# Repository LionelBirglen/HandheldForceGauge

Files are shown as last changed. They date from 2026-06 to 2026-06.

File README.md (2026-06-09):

# Handheld Force Gauge
CAD and programs for a quick and simple handheld force gauge. User interface allows for changing units (N/kg), setting tare (zeroing), recording min/max values, and switching screen orientation. Onscreen values are broadcasted with Bluetooth and a local Python script allows for realtime display and data recording into a csv file. 

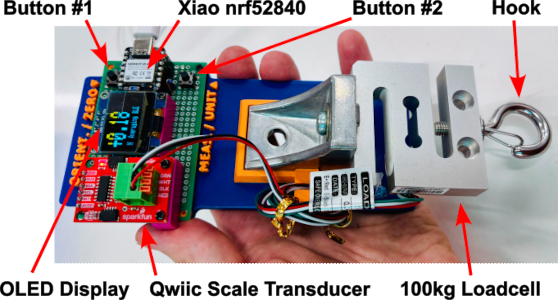
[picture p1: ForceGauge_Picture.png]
Force Gauge Picture

Force Gauge Video
<br/><br/>

## Instructions
1. 3D print ForceGauge_BasePlate.stp, Color change for the text layer is suggested
2. purchase all components, see BOM below
3. solder protoboard according to ForceGauge_Schematic.pdf
4. assemble components on protoboard
5. upload and run the Arduino program ForceGauge_Program.ino on the XIAO nrf52840 module (compile w/ mbed-enabled)
6. plug the usb-c connector to a suitable power supply
7. use the sensor! Tactile switches have two functions each, **selectable with short or long press** of the button:
8. if bluetooth communication is desired run ForceGauge_Python_BLE_Logger.py from your local machine where Python is installed, a window will open displaying the values read by the sensor and the program will record them in a csv file with timestamps.<br/>

**Notes:**
- local recording will overwrite the previous file if it exists, **rename your files if you want to keep them!**
- power can be provided by a standard phone/laptop usb-c charger or a power bank for maximal portability. Careful though, certain power banks will shut down after a short while because not enough current is pulled. Use a powerbank capable of trickle charging.
- values provided in the program are set for a 100kg load cell and need to be adjusted for your sensor and/or other load cell.
- the hook on the left of the aluminium mounting bracket is mean to hold loops of the wires from the load cell to the transducer keeping things tidy.
<br/>

## Manual
| Button # | Short Press | Long Press
|---|---|---|
| 1 | set zero (tare) | switch display orientation upside down|
| 2 | switch display unit: N or Kg |  switch recording mode: instantaneous values vs. min/max recording |
<br/>
Video demonstration: https://www.youtube.com/watch?v=c7aWqw2UN0I

## Bill of Materials (BOM)

| Name | # | Link/Description 
|---|---|---|
| XIAO nrf52840 | 1 | [SeeedStudio](https://www.seeedstudio.com/Seeed-XIAO-BLE-nRF52840-p-5201.html), need to solder male headers or purchase one with presoldered ones|
| Qwiic Scale NAU7802 | 1 |  [Sparkfun](https://www.sparkfun.com/sparkfun-qwiic-scale-nau7802.html) |
| 0.96in OLED Display | 1 |  [Amazon kit](https://www.amazon.com/ELEGOO-Display-Compact-Self-Luminous-Projects/dp/B0D2RMQQHR) |
| Protoboard | 1 | 5cm x 7cm with a 2.54mm pitch, e.g. from this [Amazon kit](https://www.amazon.com/ELEGOO-Prototype-Soldering-Compatible-Arduino/dp/B072Z7Y19F) |
| Tactile switches | 2 | [Amazon kit](https://www.amazon.com/QTEATAK-Momentary-Tactile-Button-Switch/dp/B07VSNN9S2)  |
| 3k3 resistors | 2 |  any value between 1k and 10k at 1/4W should be fine, through hole |
| Load Cell | 1 |  100kg S-shape from [Robotshop](https://www.robotshop.com/products/type-s-load-cell-100-kg) or [Amazon](https://www.amazon.com/Portable-High-Precision-Pressure-Tension-Weighing/dp/B077YHNNCP) |
| M6x12 screw w/ washer| 1 |  [Amazon kit](https://www.amazon.com/MklusiveTech-141Pcs-Screw-Kit-Electronics/dp/B0DYF25FF6) |
| CHBLFSN8 mounting bracket | 1 | Baked-on finish (Silver) 43x30 footprint with 8mm holes from [Misumi](https://us.misumi-ec.com/vona2/detail/110300449520/) |
| M6 hook | 1 | [Amazon](https://www.amazon.com/Faspiroty-Stainless-Question-Hanging-Connecting/dp/B0DKNBMYKB) (optional)  |
| Base plate | 1 |  3D printed from STEP file ForceGauge_BasePlate.stp |
| Braces | 2 |  3D printed from ForceGauge_Brace_QwiicScale.step and ForceGauge_Brace_OLEDDisplay.step |
| Self-tapping screws | 16 | for plastics, [Amazon kit](https://www.amazon.com/Zmbroll-Self-Tapping-Phillips-Sheetmetal-Electronic/dp/B0F62XS2YC)  |
| Female headers | 4 | need 1x4, 1x6, 2x7 all with 2.54mm pitch, [Amazon kit](https://www.amazon.com/Ruibapa-Connector-Assortment-Straight-P-037/dp/B0B96WXT46) |

**Notes:** 
- if you use another XIAO microcontroller the Arduino program might need to be updated especially if the one you pick has no Bluetooth capability
- the CHBLFSN8 mounting bracket used here is meant for 4040 extrusions but other mounting brackets for either 4040 or 3030 profiles could also be used and might be easier/cheaper to find than Misumi's. Adjust the size of the rectangular hole in the base plate STP file accordingly. File down the tabs of the bracket you used if there are any.
- check the components you have laying around before buying the kits listed in the BOM, most components here such as tactile switches, resistors, M6 screws, etc. do not need to be the exact model from the BOM, if you have already some parts at hand you can probably use them.
<br/>

## Arduino Library Requirements
SparkFun Qwiic Scale NAU7802<br/>
Adafruit GFX<br/>
Adafruit SSD1306<br/>
PushButtonTaps<br/>
ArduinoBLE<br/>
<br/>

by Lionel Birglen  <br />
Polytechnique Montreal, 2026
License: GNU GPL v3

###  DISCLAIMER:
This hardware and software project is provided "as is", and at your own risk. Under no circumstances shall any author be liable for direct, indirect, special, incidental, or consequential damages resulting from the use, misuse, or inability to use this hardware/software, even if the authors have been advised of the possibility of such damages.

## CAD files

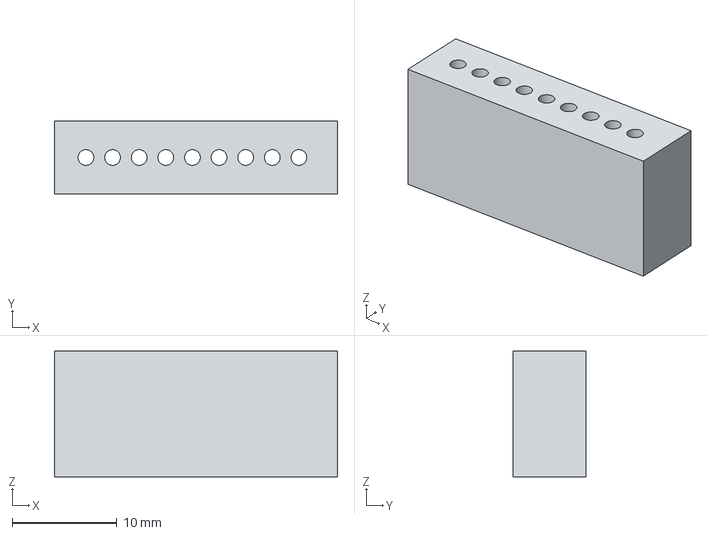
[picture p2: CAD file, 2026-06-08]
ForceGauge_Brace_QwiicScale.stp
27.0 x 7.00 x 12.0 mm

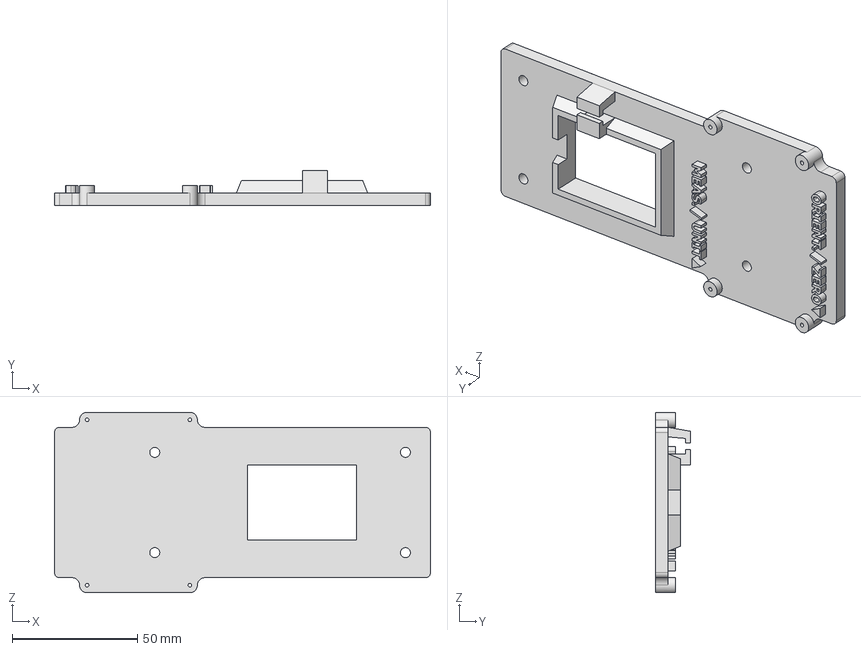
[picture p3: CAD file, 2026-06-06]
ForceGauge_BasePlate.stp
150.0 x 14.0 x 72.0 mm

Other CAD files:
ForceGauge_Brace_OLEDDisplay.stp

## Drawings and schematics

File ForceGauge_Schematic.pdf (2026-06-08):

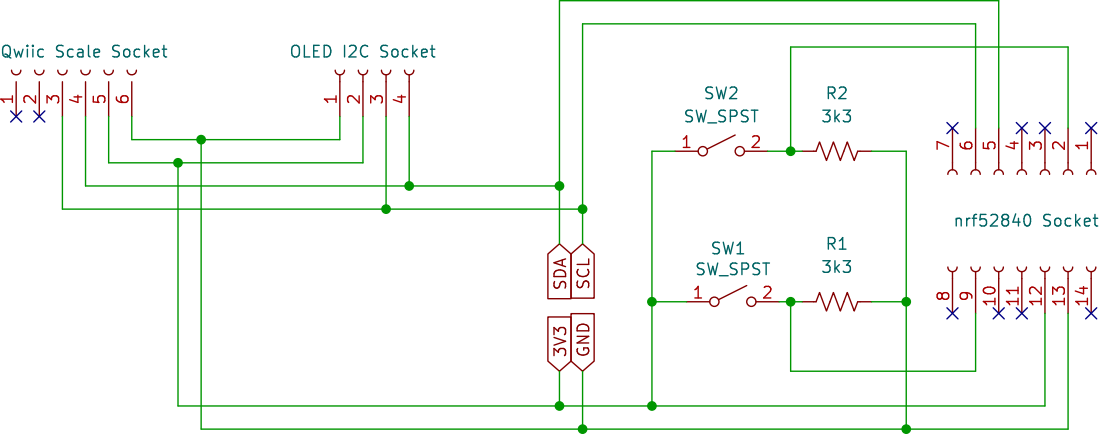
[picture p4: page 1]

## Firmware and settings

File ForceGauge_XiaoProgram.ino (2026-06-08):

/*
  Handheld Force Gauge
  
  Record and translate force values from a force sensor connected to a NAU7802 transducer module.
  Values are displayed on a SSD1306 128x32 OLED display connected to the i2c bus as the NAU7802 transducer.
  Two tactile switch connected to digital input D2 and D9 serve as a user interface and each button 
  has two functions which are triggered by either a short or long push of the button. Values are 
  broadcasted on Bluetooth.
  
  Default values and calibration data are for use with a 100kg force sensor.
  
  by Prof. Lionel Birglen
  Polytechnique Montreal, 2025
*/

#include <Wire.h>
#include "SparkFun_Qwiic_Scale_NAU7802_Arduino_Library.h"
#include <Adafruit_GFX.h>
#include <Adafruit_SSD1306.h>
#include <PushButtonTaps.h>
#include <ArduinoBLE.h>

#define SCREEN_WIDTH 128
#define SCREEN_HEIGHT 32  //Yes the screen actual height is 64
#define OLED_RESET     -1
#define SCREEN_ADDRESS 0x3C

//OLED object creation
Adafruit_SSD1306 display(SCREEN_WIDTH, SCREEN_HEIGHT, &Wire, OLED_RESET);

//Force gauge interface object creation
NAU7802 myScale;

//Pushbutton object creation
PushButtonTaps pushBtn1;
PushButtonTaps pushBtn2;

//Pin number for pushbutton
int pushButton1 = D2;
int pushButton2 = D9;

//Constant definition
const double kgs = 0.101936799184506;         //kgs to newtons coefficient
const unsigned long inhibitUnitChange = 500;  //when switching units, how long before another change can be made
const double newtons = 1;                     //Newtons to newtons coefficient lol
const int n_samples = 120;                    //Number of measurements to be averages

//Variable definition
int activeSerial = 1;
int activeBluetooth = 1;
int operationMode = 1;                        //averaging or peak mode
unsigned long lastUnitSwitch = 0;             //time of last unit switch
double measUnit = 1;                          //index of unit
int32_t currentBias = 5500;//1200;            //offset reading, updated when pussing the zeroing button
const double m_scale = 0.000228;//0.000227;   //force scaling
int32_t currentReading = 0;                   //current force readings unitless
int32_t maxReading = 0;                       //current max value recorded (long integer)
int32_t minReading = 2147483647;              //current min value recorded (long integer)
double currentReadingFloat = 0;               //current force reading with unit
double minReadingFloat = 0;                   //current min value recorded (double float)
double maxReadingFloat = 0;                   //current max value recorded (double float)
uint8_t orientation = 0;                      //Integer for screen orientation

//Bluetooth definitions
BLEService scaleService("19B10010-E8F2-537E-4F6C-D104768A1214");  // Custom 128-bit UUIDs (can be changed)
BLEFloatCharacteristic forceCharacteristic(
  "19B10011-E8F2-537E-4F6C-D104768A1214",
  BLERead | BLENotify
);

void setup()
{
  Serial.begin(115200);
  delay(100);

  Serial.println("Force Gauge Sensing");

  //Bluetooth intialization
  if (!BLE.begin()) {
    Serial.println("Starting BLE failed!");
    activeBluetooth=0;
  }

  BLE.setLocalName("Force Gauge");          //Bluetooth device name
  BLE.setAdvertisedService(scaleService);   //Service advertisement
  scaleService.addCharacteristic(forceCharacteristic);
  BLE.addService(scaleService);
  forceCharacteristic.writeValue(0.0f);   // initial value
  BLE.advertise();                        // start advertising

  Serial.println("Bluetooth ready, advertising force sensor");

  //Pushbutton definition as active high
  pushBtn1.setButtonPin(pushButton1);
  pushBtn1.setButtonActiveLow(false);
  pushBtn2.setButtonPin(pushButton2);
  pushBtn2.setButtonActiveLow(false);

  //I2C Initialization
  Wire.begin();

  //Generate 3.3V display voltage internally
  if (!display.begin(SSD1306_SWITCHCAPVCC, SCREEN_ADDRESS)) {
    Serial.println(F("SSD1306 allocation failed"));
  }
  display.clearDisplay(); //Start by clearing the screen

  //Force gauge initialization
  if (myScale.begin() == false)
  {
    Serial.println("Scale not detected. Stopping here.");
    while (1);                                              //Stop everything
  }
  Serial.println("Scale detected!");
  display.setTextColor(SSD1306_WHITE);
}

void loop()
{
  unsigned long currentTime = millis();

  if (!Serial) {activeSerial=0;} else {activeSerial=1;};

  BLE.poll();   //keep BLE stack alive

  //Read pushbuttons
  byte tap1 = pushBtn1.checkButtonStatus();
  byte tap2 = pushBtn2.checkButtonStatus();

  //Debug outputs:
//  Serial.print("Button 1: ");
//  Serial.println(tap1);
//  Serial.print("Button 2: ");
//  Serial.println(tap2);

  //Force sensor read 
  if (myScale.available() == true)
  {
    //Read n_samples times the force sensor and sum all values
    for (int i = 1; i <= n_samples; i++) {
      currentReading += myScale.getReading();
      delay(1);
    }

    //If zeroing button is pushed, set current bias to the current average reading
    if (tap1 == 1) {
      currentBias = -(currentReading / n_samples);
      maxReading = 0;
      minReading = 2147483647;
    }

    //If unit change button is pressed, switch units and deactivate function for 0.5s
    if (tap2 == 1) {
      if (currentTime - lastUnitSwitch > inhibitUnitChange) {
        if (measUnit == newtons) measUnit = kgs;
        else measUnit = newtons;
        lastUnitSwitch = currentTime;
      }
    }

    //If long press on zeroing button, switch screen orientation
    if (tap1 == 3) {
      switch (orientation) {
        case 0:
          orientation = 2;
          break;
        case 2:
          orientation = 0;
          break;
      }
      display.setRotation(orientation);
    }

    //If long press on unit button, switch operation mode
    if (tap2 == 3) {
      switch (operationMode) {
        case 1:
          operationMode = 2;        
          break;
        case 2:
          operationMode = 1;
          break;
      }
    }

    //Average all measurements and convert to newtons 
    currentReading = (currentReading / n_samples) + currentBias;
    currentReadingFloat = measUnit * m_scale * currentReading;

    //Compare to previously stored peak values
    if (operationMode==2) {
      if (currentReading>maxReading) {maxReading=currentReading;maxReadingFloat=measUnit * m_scale * maxReading;}
      if (currentReading<minReading) {minReading=currentReading;minReadingFloat=measUnit * m_scale * minReading;}  
    }
    
    //Publish readings on serial port
    Serial.print("Active Serial / Bluetooth : ");
    Serial.print(activeSerial);
    Serial.print("/");
    Serial.print(activeBluetooth);
    Serial.println();
    Serial.print("Current bias : ");
    Serial.println(currentBias);
    Serial.print("Raw reading in current mode: ");
    Serial.println(currentReading);
    Serial.println("Min/Max Raw reading: ");
    Serial.print(minReading);
    Serial.print("/");
    Serial.println(maxReading);
    Serial.print("Average reading with current unit: ");
    Serial.println(currentReadingFloat);
    Serial.println("Min/Max reading with current unit: ");
    Serial.print(minReadingFloat);
    Serial.print("/");
    Serial.println(maxReadingFloat);

    //Display on OLED
    display.clearDisplay();
    switch (operationMode) {
        case 1:
          display.setCursor(0, 0);
          display.setTextSize(3);
          char buf[64];
          sprintf(buf, "%.2f", currentReadingFloat);
          if (currentReading < 0)
          {
            display.println(buf);
          }
          else
          {
            display.print('+');   //Add a + sign if value is positive, cleaner to look at
            display.println(buf);
          } 
          break;
        case 2:
          display.setCursor(0, 0);
          display.setTextSize(2);
          char buf2[64];
          sprintf(buf2, "%.2f", minReadingFloat);
          if (minReading < 0)
          {
            display.println(buf2);
          }
          else
          {
            display.print('+');   //Add a + sign if value is positive, cleaner to look at
            display.println(buf2);
          }   
          display.setCursor(0, 18);
          display.setTextSize(2);
          char buf3[64];
          sprintf(buf3, "%.2f", maxReadingFloat);
          if (maxReading < 0)
          {
            display.println(buf3);
          }
          else
          {
            display.print('+');   //Add a + sign if value is positive, cleaner to look at
            display.println(buf3);
          }   
          break;
      }
    

    //Display current unit onscreen
    display.setTextSize(1);
    switch (operationMode) {
      case 1:
      if (measUnit == newtons) {
        display.setCursor(0, 24);
        display.print(" N");
      } 
      else {
        display.setCursor(0, 24);
        display.print("KG");
      }
    break;
    case 2:
    if (measUnit == newtons) {
        display.setCursor(111, 0);
        display.print(" N");
      } 
      else {
        display.setCursor(111, 0);
        display.print("KG");
      }
    break;
    }
    
    //Display information
    display.setTextSize(1);
    switch (operationMode) {
      case 1:
      display.setCursor(23, 24);
      display.print("Averaging");
      if (activeBluetooth==1) {
        display.setCursor(85, 24);
        display.print("BLE ");
      }
      if (activeSerial==1) {
        display.setCursor(105, 24);
        display.print("SER");
      }
      break;
      case 2:
        display.setCursor(102, 8);
        display.print("Peak");
        if (activeBluetooth==1) {
        display.setCursor(105, 17);
        display.print("BLE");
      }
      if (activeSerial==1) {
        display.setCursor(105, 25);
        display.print("SER");
      }
      break;
    }

    //Put everything on screen
    display.display();
  }

  //Bluetooth update
  forceCharacteristic.writeValue((float)currentReadingFloat);
}

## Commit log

2026-06-08 Add Bill of Materials section to README
    Added a new section for Bill of Materials (BOM) in README.
2026-06-08 Clarify instructions for uploading Arduino program
2026-06-08 Update README with additional instructions
    Added instructions for 3D printing and component purchase.
